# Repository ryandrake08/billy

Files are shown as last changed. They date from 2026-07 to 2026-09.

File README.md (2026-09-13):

# Smart Mouth Billy Bass LLM jokester

Billy is a Big Mouth Billy Bass novelty toy converted into an **offline, LAN-only** voice
jokester. An ESP32-S3 inside the fish captures speech, drives the motors, and plays back
audio; a separate GPU box does speech-to-text, LLM inference, and text-to-speech. There is no
internet dependency anywhere in the pipeline.

The fish's' persona, conversation history, text cleanup, and configuraion all live on the
backend, in an business-logic "shim" application in front of the LLM. The fish just captures
audio, makes three HTTP calls per turn, plays the reply, and animates the mouth/head/tail in
sync with it.

## Architecture

```
        FISH (ESP32-S3)                                BACKEND (LAN)
  ┌──────────────────────────┐                  ┌───────────────────────────┐
  │ mic → capture utterance  │─── utterance ───▶│ whisper.cpp        :8081  │
  │                          │◀───── text ──────│                           │
  |                          |                  |                           |    ┌─────────────────┐
  │ text → shim              │────── text ─────▶│ shim (persona,     :8000  │──▶ | llama.cpp :8080 |
  │                          │◀─── response ────│  history, text cleaning)  │    └─────────────────┘
  │                          │                  │                           │
  │ sentence → TTS           │──── sentence ───▶│ Kokoro             :8880  │
  │                          │◀──── audio ──────│                           │
  │ amp + motors             │                  └───────────────────────────┘
  └──────────────────────────┘
```

Three calls per conversational turn:

| Call | Target | Request → Response |
|---|---|---|
| STT | whisper.cpp `:8081`, direct | `POST /inference` (multipart wav, `response_format=verbose_json`, `language=auto`) → `{"text", "detected_language", ...}` |
| brain | shim `:8000` | `POST /v1/respond` `{session, text, language}` → SSE stream of `{"sentence", "voice"}` |
| TTS | Kokoro `:8880`, direct | `POST /v1/audio/speech` `{model, input, voice}` → wav bytes |

STT and TTS are dumb audio↔text transforms called **directly**; only the brain hop goes through
the shim, which is a text-only service that never touches audio. The shim streams sentences as
the LLM generates them, so the caller can synthesize and play sentence 1 while sentence 2 is
still being generated — this pipelining is what keeps time-to-first-audio low.

There are three implementations of this protocol, and they should be indentical: the reference clients
`src/client/billy_cli.py` (Python) and `src/cli/` (C), and the ESP32 firmware
(`src/firmware/main/net.c`). The CLIs exist to document the protocol the firmware has to match —
the C one doubles as a check on how much of the firmware's own protocol code (WAV header,
hand-rolled JSON parsing, SSE reassembly) is genuinely ESP-IDF-independent and portable to a
host build; it turned out to be all of it.

## Repository layout

| Path | What |
|---|---|
| `board/` | Custom PCB for the fish's electronics (KiCad). |
| `src/firmware/` | ESP32-S3 firmware (C, ESP-IDF). |
| `src/shim/` | Backend application-logic layer (Python/FastAPI). |
| `src/client/` | CLI reference client (Python) — a mic+speaker stand-in for the fish. |
| `src/cli/` | CLI reference client (C) — built against libcurl/PortAudio/soxr. |
| `src/tests/` | End-to-end integration test for the multi-language STT→shim→LLM pipeline. |

---

## `board/` — Custom PCB

KiCad project at `board/billy/`. Replaces the toy's stock control board with a single board
carrying the ESP32-S3, motor drivers, amp, buck regulator, and power-input protection,
designed to fit inside the original toy's chassis (~70×50mm).

| Part | Role |
|---|---|
| ESP32-S3-WROOM-1-N4R2 | Controller — WiFi, dual I²S, deep sleep |
| TDK ICS-43434 (I²S MEMS mic) | Microphone — mounted as a separate satellite board, off the main PCB, for acoustic placement |
| MAX98357A (I²S class-D amp) | Speaker drive |
| 2× TI DRV8833 (dual H-bridge) | 3 motor channels — mouth, head, tail (all spring-return, unidirectional) |
| DIODES AP63203 buck | 6V → 3.3V logic/audio rail |
| AOS AO3401A / AO3400A FETs (battery reverse-polarity protection, USB/motor-rail isolation pass FET, status LED + photocell/Vmotor-sense divider gating) | Power-input protection and deep-sleep peripheral gating |
| Analog Devices LTC4412 | Ideal-diode controller — motor rail vs. USB arbitration into the buck |
| MCC B5817W Schottky | Passive ideal diode — USB VBUS into the buck |
| 2× 5A slow-blow fuses | Battery and DC-jack input protection |

The KiCad schematic and PCB are authoritative for hardware connectivity and layout. Firmware
`board.h` mirrors the schematic's GPIO assignments and must stay synchronized with it.

**Workflow:**
```bash
open board/billy/billy.kicad_pro
kicad-cli sch erc --format json --severity-all -o erc.json board/billy/billy.kicad_sch
kicad-cli pcb drc --format json --severity-all --schematic-parity -o drc.json board/billy/billy.kicad_pcb
```

---

## `src/firmware/` — ESP32-S3 firmware

Captures speech, calls the backend for STT → LLM → TTS, plays the reply, and drives the
mouth/head/tail motors in sync with it. Targets `esp32s3` (tested with ESP-IDF v6.0.2).

### Layering

| Layer | Files | Responsibility |
|---|---|---|
| app | `main.c` | `app_main()` wires everything together; `runloop_task` runs the `IDLE→ACTIVATE→LISTEN→THINK→SPEAK→IDLE` state machine. |
| transport | `net.c/.h` | The fish↔backend contract described above — STT direct, brain hop through the shim, TTS direct. |
| device | `audio.c/.h`, `motors.c/.h`, `activation.c/.h`, `peripherals.c/.h` | Fish-specific setup and algorithms built on the HAL: I²S mic/amp + mouth lip-sync envelope; 2× DRV8833 motor choreography with `nFAULT` telemetry and deferred Vmotor capture; button/mode-switch/wake-word activation + deep sleep; WS2812 status LED + photocell/Vmotor-sense reads, all gated by one shared enable line. |
| HAL | `hal.c/.h` | Generic, pin-parameterized primitives (GPIO, ADC1, LED strip, PWM, I²S, deep sleep) with no fish-specific naming and no `board.h` dependency of its own. |

`board.h` is the firmware representation of the schematic pin map. `components/wakeword` is the on-device
wake-word detector (TensorFlow Lite Micro, ported from ESPHome's `micro_wake_word` component). See its own
`models/ATTRIBUTION.md` for training provenance.

### Build

```bash
source ~/.espressif/tools/activate_idf_v6.0.2.sh
cd src/firmware
export WIFI_SSID="your-2.4GHz-ssid" WIFI_PASSWORD="your-password" BACKEND_HOST="your-backend-hostname-or-ip"
idf.py set-target esp32s3      # once
idf.py build
idf.py -p <port> flash monitor
```
WiFi credentials and the backend host are build-environment variables injected as compile
definitions (`main/CMakeLists.txt`). Changing one needs `idf.py reconfigure`. `./clean.sh`
removes all generated build state.

### Debug

Step-debug with breakpoints over the S3's native USB-Serial-JTAG:
```bash
openocd -f board/esp32s3-builtin.cfg    # terminal 1
idf.py -p <port> gdb                    # terminal 2
```
The DevKitC-1 has two USB ports — flashing uses the UART/CP2102 port; OpenOCD needs the
separate native-USB port instead. The production board has a USB port and a three pin
header (TTL level) to one of the ESP32's built-in UARTs. Only use a USB-to-UART cable that
uses 3.3V with this header! In addition to the direct-to-UART header, the production board
has a two pin header for firmware flashing. Jumping the header during a reset causes the chip
to enter UART download (flashing) mode instead of booting normally from flash memory.
The UART/FLASH headers are intended to be a backup in case flashing over USB fails, and the
header can be left unpopulated if unused.

### Runtime behavior

`runloop_task` starts immediately on boot and idles waiting for activation; it does not block
on WiFi or the backend being reachable. Activation depends on the mode switch: **button mode**
(press-to-talk, deep-sleeps between turns) or **wake-word mode** (mic stays live, listens for
"hey billy"; a button press also works as a manual override). Flipping the switch mid-wait
preempts immediately. Runtime-tunable constants (VAD thresholds, mouth/tail timing, and HTTP
timeouts) are fetched from the shim's `/v1/config` every loop cycle rather than compiled
in, with compiled-in fallbacks if the shim is unreachable. Each capture's VAD threshold adapts
to the room's ambient noise level, measured during the pre-capture drain window, so a noisy
room still reads as silence once the user stops talking. The DRV8833 `nFAULT` line is logged but
does not gate motor commands because it asserts unreliably on the board; the drivers' independent
silicon overcurrent, thermal, and undervoltage protection remains active.

---

## `src/shim/` — backend application-logic layer

The brain layer in front of `llama.cpp`. Holds the application logic that has to live off the
fish for it to stay a thin client:

- **persona** / system prompt — edit `text.py`, reload;
- **conversation history / session state** — kept server-side, keyed by session id;
- **model quirks** — the `enable_thinking` request flag and `<think>`-block stripping;
- **markdown/emoji scrubbing** — the LLM still emits stray formatting that TTS would mangle;
- **sentence splitting + streaming** — emits clean sentences as they're ready so the caller can
  pipeline TTS for low first-audio latency;
- **per-language voice routing** (`text.py`'s `LANGUAGE_VOICES`) — English (`am_onyx`) plus
  Spanish, Brazilian Portuguese, Mandarin, Japanese, Hindi, and Italian, picked from the caller's
  detected language and overridable per sentence for an explicit switch mid-reply;
- **runtime firmware config** (`fish_config.py`) — tunable firmware constants served over
  `GET /v1/config`, so they can be retuned without a reflash.

### Protocol

| Call | Request | Response |
|---|---|---|
| `POST /v1/respond` | `{"session": "default", "text": "<user utterance>", "language": "english"}` | `text/event-stream`: one `data: {"sentence": ..., "voice": ...}` per spoken sentence, then `data: [DONE]` |
| `POST /v1/reset` | `{"session": "default"}` | `{"reset": "<session>"}` |
| `GET /v1/config` | — | Runtime firmware-tunable constants |
| `GET /health` | — | `{status, llm_url, llm_model, llm_reachable, sessions}` |

### Run

```bash
cd src/shim
python3 -m venv .venv && .venv/bin/pip install -r requirements.txt
.venv/bin/uvicorn billy_shim:app --host 0.0.0.0 --port 8000
```
Config via env: `BILLY_LLM_URL` (default `http://localhost:8080`), `BILLY_LLM_MODEL` (default
`Qwen3.5-9B`). Tests use plain asserts rather than pytest:

```bash
.venv/bin/python test_text.py
.venv/bin/python test_config.py
.venv/bin/python test_session.py
```

### Deploy

Shim program can live anywhere. Recommend using your OS's init system to start and manage it.

---

## `src/client/` — CLI reference client (Python)

A command-line stand-in for the fish: drives the full backend pipeline (record → STT → shim →
TTS → play) from any host with a mic and speaker.

### Run

```bash
cd src/client
python3 -m venv .venv && . .venv/bin/activate && pip install -r requirements.txt
./billy_cli.py --host <backend-host>     # ports 8000/8081/8880 derived from host
```
Press **Enter** to start talking, speak, press **Enter** to stop. `Ctrl-C` quits.

`--voice <kokoro-voice>` overrides the voice for the whole session (browse the list at
`http://<backend-host>:8880/web`); otherwise each sentence uses the shim's own per-sentence
choice. `--session <id>` sets the shim conversation id; `--shim-url`/`--stt-url`/`--tts-url`
override individual endpoints. Uses the system default audio devices.

`--input-wav <path>` skips the mic entirely: runs one turn on that WAV file's bytes (16 kHz mono,
same as the mic path itself records) and exits — for testing the same utterance repeatedly
without re-recording it by hand each time.

Each turn prints various latency measurements.

---

## `src/cli/` — CLI reference client (C)

A second, independent reference client for the same contract — same record → STT → shim → TTS →
play pipeline as the Python client, same flags, same latency breakdown, but built as a plain C
binary via CMake instead of a Python venv.

External dependencies (none of this is vendored): `libcurl` (HTTP, mirrors `httpx`), `portaudio`
(mic/speaker I/O, mirrors `sounddevice`), `soxr` (output resampling, same library the Python
`soxr` package binds to). On macOS via MacPorts: `port install curl portaudio soxr`.

### Build & run

```bash
cd src/cli
cmake -S . -B build && cmake --build build
./build/billy_cli --host <backend-host>     # ports 8000/8081/8880 derived from host
```
Press **Enter** to start talking, speak, press **Enter** to stop. `Ctrl-C` quits, same as the
Python client.

Same `--voice`/`--session`/`--shim-url`/`--stt-url`/`--tts-url` flags as the Python client, same
system-default audio devices. TTS audio is resampled to the output device's native rate in
software (soxr, `SOXR_HQ` quality).

---

## `src/tests/` — end-to-end integration test

Exercises the  STT→shim→LLM chain for every supported language. For each language, a
"golden" WAV asking Billy to repeat a fixed phrase is transcribed by real whisper.cpp, then sent
to a shim, checking the reply comes back in the right voice and language.

```bash
cd src/tests
python3 -m venv .venv && .venv/bin/pip install -r requirements.txt
./.venv/bin/python test_language_integration.py     # needs src/shim/.venv already set up
```

The golden WAVs in `golden/` are gitignored: `generate_golden.py` makes them with Microsoft's
free `edge-tts`. The test does this itself the first time golden/ is missing a file.

---

## Backend engines

Three off-the-shelf inference engines run on the backend GPU host alongside the shim, all under
systemd (`Restart=always`, enabled at boot):

| Service | Port | Model | GPU |
|---|---|---|---|
| llama.cpp | 8080 | Qwen3.5-9B, Q8_0, non-thinking mode | yes |
| whisper.cpp | 8081 | `large-v3` | yes |
| Kokoro (Kokoro-FastAPI) | 8880 | `am_onyx` + 6 other language voices (see `src/shim/`) | yes |

All three plus the shim are expected to fit resident in ~14GB of VRAM.

---

## License

Source code and documentation are licensed under [Apache License 2.0](LICENSE). The
trained wake-word model `src/firmware/components/wakeword/models/hey_billy.tflite` is
explicitly excluded; see [NOTICE](NOTICE) and its
[`ATTRIBUTION.md`](src/firmware/components/wakeword/models/ATTRIBUTION.md).

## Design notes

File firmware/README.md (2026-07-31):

# Billy fish firmware (ESP32-S3)

The on-fish firmware. Captures speech, calls the backend for STT → LLM → TTS, plays the reply,
and drives the mouth/head/tail motors in sync with it. Runs on an ESP32-S3-WROOM-1 N8R8, target
`esp32s3`, no persona or conversation state on-device — see the top-level `CLAUDE.md` for how this
fits into the rest of the project.

## Layering

Three layers, each with a single responsibility:

| Layer | Files | Responsibility |
|---|---|---|
| **app** | `main.c` | `app_main()` wires the layers together; `runloop_task` runs the `IDLE→ACTIVATE→LISTEN→THINK→SPEAK→IDLE` state machine. |
| **transport** | `net.c/.h` | The fish↔backend contract — STT (whisper), brain (shim), TTS (Kokoro). WiFi join/reconnect is async and unbounded, supervised by a dedicated task for the app's whole runtime. |
| **hardware** | `hal.c/.h`, `board.h`, `components/wakeword` | Mic/amp I²S, 2× DRV8833 motors, button/switch/photocell, wake-word detection. `board.h` is the pin map. |

The transport layer mirrors the three calls the CLI reference client makes
(`client/billy_cli.py`), so the fish reimplements the same contract.

## Build

```bash
source ~/.espressif/tools/activate_idf_v6.0.2.sh   # activate ESP-IDF v6.0.2
cd firmware

# WiFi credentials and the backend host come from the build environment, never source control
# (main/CMakeLists.txt injects them as compile definitions). BACKEND_HOST is required; export
# these BEFORE set-target — it runs a CMake configure that fails without BACKEND_HOST.
export WIFI_SSID="your-2.4GHz-ssid"
export WIFI_PASSWORD="your-password"
export BACKEND_HOST="your-host-or-ip"

idf.py set-target esp32s3      # once (configures + writes sdkconfig from sdkconfig.defaults)
idf.py build                   # without WiFi creds it warns and can't join WiFi; BACKEND_HOST is required
```

Changing an exported value needs `idf.py reconfigure` (CMake reads the environment at configure
time). Flash + watch the boot log:

```bash
idf.py -p <port> flash monitor
```

Use `./clean.sh` to remove all generated/fetched build state (`build/`, `.cache/`,
`managed_components/`, `dependencies.lock`, `sdkconfig`, `sdkconfig.old`) and start fresh.

## Debug

Step-debug with real breakpoints over the S3's native USB-Serial-JTAG, no extra hardware:

```bash
openocd -f board/esp32s3-builtin.cfg    # terminal 1 — leave running
idf.py -p <port> gdb                    # terminal 2
```

The DevKitC-1 has **two** USB-C ports — flashing via `idf.py flash` (above) uses the **UART**
port (the CP2102 bridge), but OpenOCD needs the separate **USB** port instead, wired straight to
the S3's native USB-Serial-JTAG peripheral. Plugging into the wrong port shows up as OpenOCD
failing with `could not find or open device!` — check `system_profiler SPUSBDataType` (macOS) for
a `303a:1001` device to confirm you're on the right one. That port also carries USB power, so
debug sessions have the same constraint as USB flashing: keep the battery/buck disconnected while
it's plugged in.

## Runtime behavior

`runloop_task` starts immediately on boot and idles in `FISH_IDLE` waiting for activation — it
does not wait for WiFi to join or the backend to become reachable first (look for `got IP …` in
the log once WiFi is up). A turn that needs the network before it's ready just fails that one turn
(error tone, back to idle) rather than blocking startup; a dropped connection at any point during
runtime is retried indefinitely with backoff by a dedicated task.

Activation depends on `BOARD_MODE_SW`:
- **Button mode** — a `BOARD_BUTTON` press starts a turn. Between turns the fish deep-sleeps (mic
  and status LED off, motors parked) and wakes on the next button press.
- **Wake-word mode** — the mic stays live and a turn starts on the "hey billy" phrase
  (`components/wakeword`, on-device TensorFlow Lite Micro). A button press also works here as a
  manual override.

Flipping the mode switch mid-wait preempts an in-progress wait immediately in either direction.

Each turn drives all three motors (mouth/head/tail) in sync with the reply audio and plays it
through the amp; the photocell is read at boot and available via `fish_hal_read_photocell()`, with
no consumer wired up yet. See `board.h` for the pin map and `WIRING.md` for driver and mechanism
details.

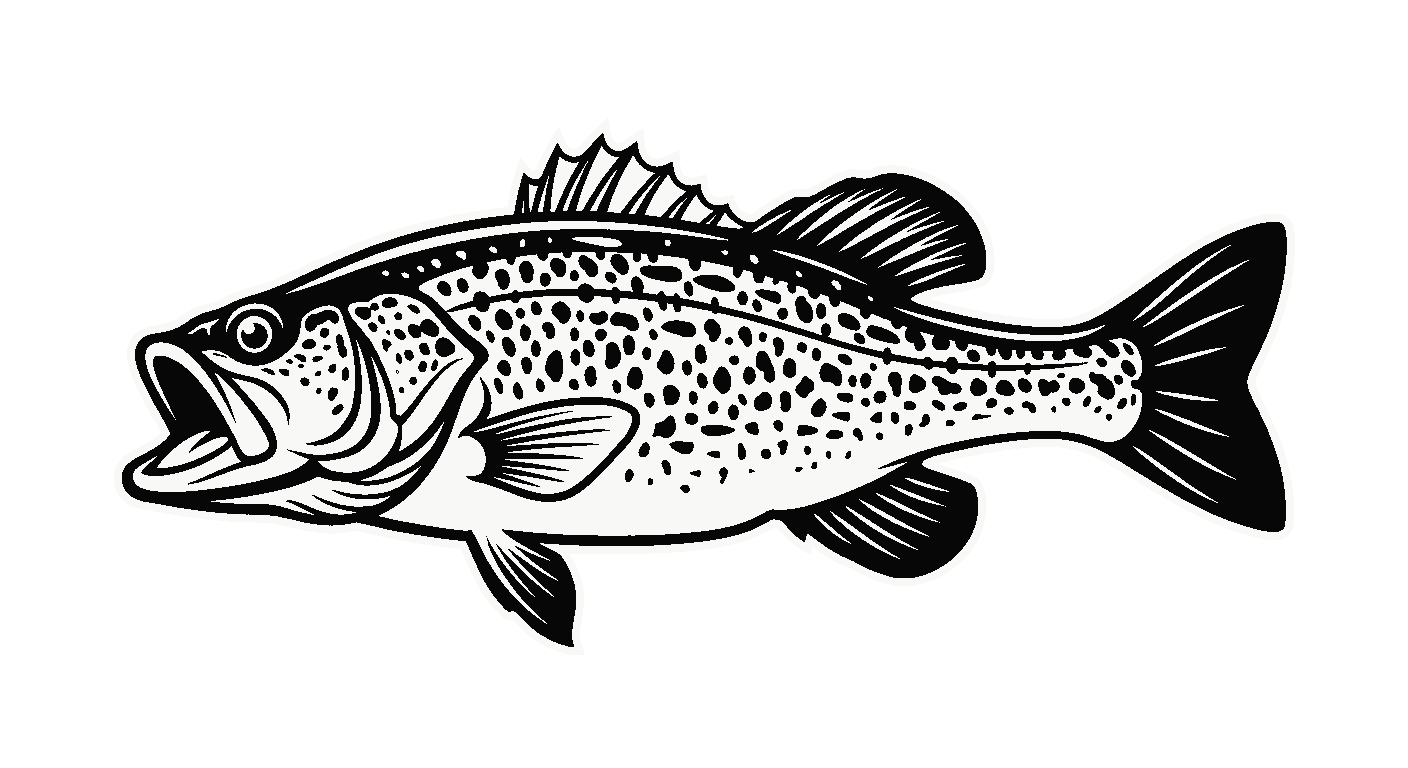
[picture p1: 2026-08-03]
board/billy/billy.png

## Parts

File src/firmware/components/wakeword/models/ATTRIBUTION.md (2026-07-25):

`hey_billy.tflite` — our own trained microWakeWord v2 model for "hey billy", trained 2026-07-24.

Training framework: `OHF-Voice/micro-wake-word` (Apache-2.0). Positive samples generated with
`rhasspy/piper-sample-generator`
(TTS, 1000 samples, `en_US-libritts_r-medium` voice); negative data from the framework's
pre-built HuggingFace sets (`speech`, `dinner_party`, `no_speech`, `dinner_party_eval`) plus MIT
room-impulse-response and FMA background-noise augmentation of the positive samples. Trained on
`gpu-host` in an isolated, disposable `/opt/training` tree — not part of this repo or the
firmware build; only this `.tflite` file is a build input.

Manifest values — keep these in sync with the `WAKEWORD_*` constants in `wakeword.cpp` if the
model is ever retrained:

```json
{
  "probability_cutoff": 0.84,
  "feature_step_size": 10,
  "sliding_window_size": 5,
  "tensor_arena_size": 33540
}
```

`probability_cutoff` chosen from the training run's ROC sweep: 5% false-reject rate, ~0.19 false
accepts/hour on the (synthetic) validation set. `sliding_window_size` matches the training
framework's own test-harness default (`microwakeword/test.py`, `sliding_window_length=5`).
`tensor_arena_size` is measured on-device (`wakeword_init()`'s logged `arena_used_bytes()`), not
taken from any manifest — arena sizing is not portable across TFLM builds, or even between two
models on the same build. Always re-derive it empirically if the model is ever retrained.

Real-world false-accept/false-reject rates will very likely differ from the synthetic validation
numbers above — expect to retrain (more/better samples, reweighted negatives, retuned cutoff) if
bench testing shows the model is too trigger-happy or too hard to wake.

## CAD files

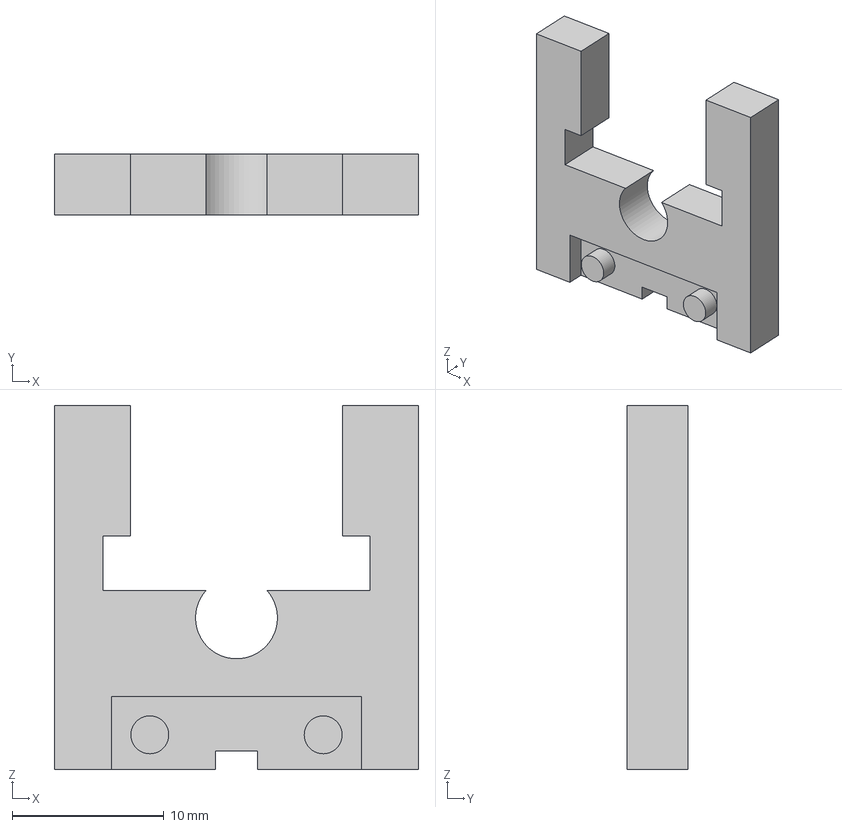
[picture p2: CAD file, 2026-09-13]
board/caddy/caddy.step
24.0 x 4.00 x 24.0 mm

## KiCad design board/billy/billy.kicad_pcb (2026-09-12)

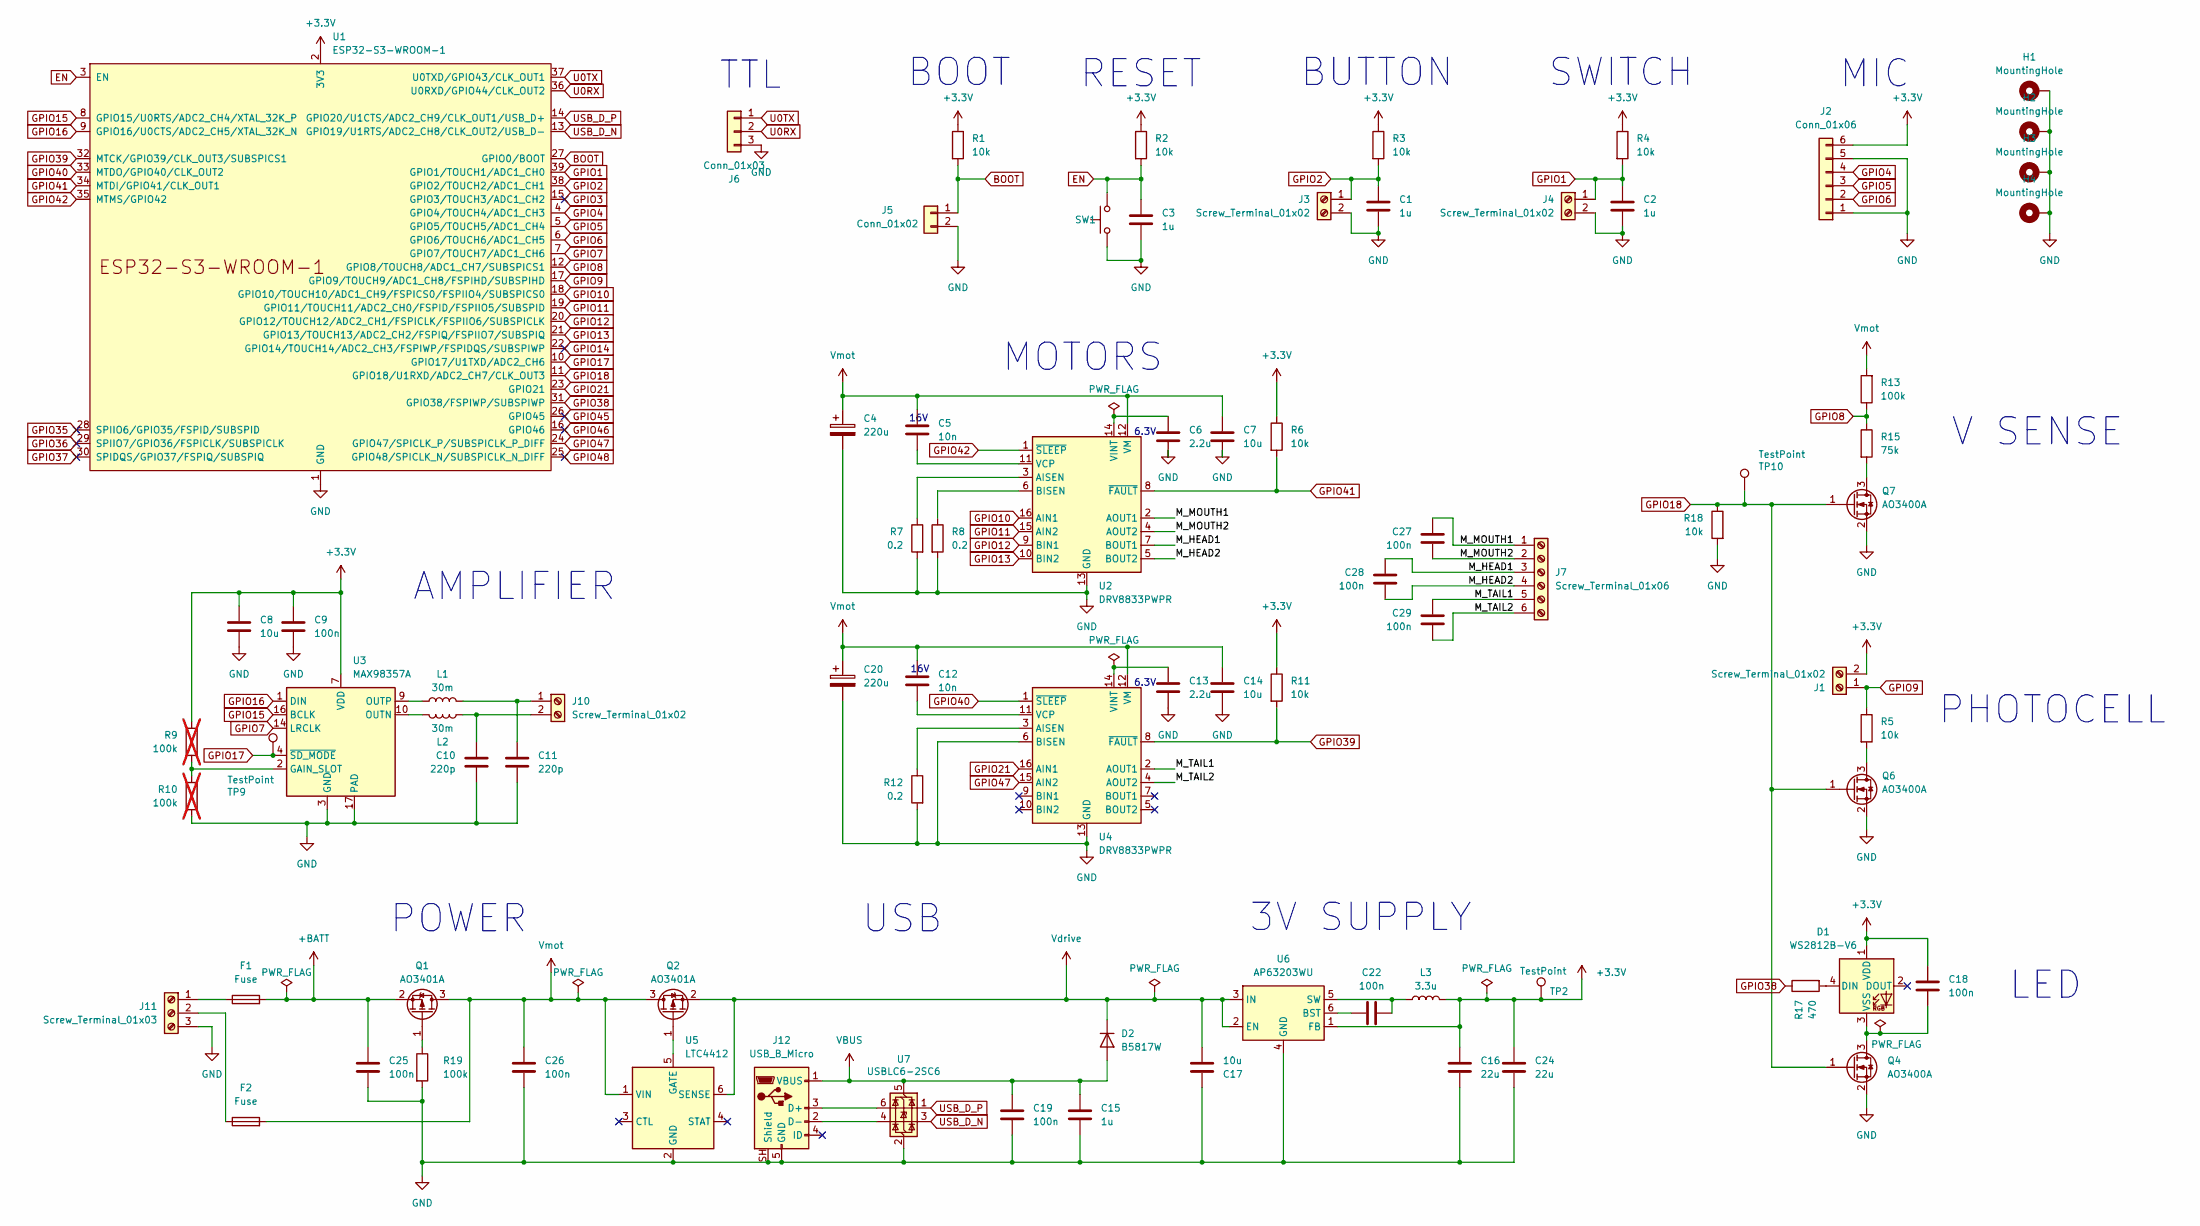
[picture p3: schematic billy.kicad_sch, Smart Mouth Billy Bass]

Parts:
C1, C2, C3, C15: 1u; C_0603_1608Metric; Mouser Part 187-CL10B105KP8NNNC; LCSC Part C52923
C4, C20: 220u; CP_Elec_6.3x5.9; Mouser Part 667-EEE-FT1C221AP; LCSC Part C401766
C5, C12: 10n; C_0603_1608Metric; Mouser Part 187-CL05B103KB5NNNC; LCSC Part C15195
C6, C13: 2.2u; C_0603_1608Metric; Mouser Part 187-CL10A225KP8NNNC; LCSC Part C23630
C7, C8, C14: 10u; C_0603_1608Metric; Mouser Part 187-CL10A106KP8NNND; LCSC Part C19702
C9, C18, C19, C22, C25, C26, C27, C28, C29: 100n; C_0603_1608Metric; Mouser Part 187-CL10B104JB8NNNC; LCSC Part C1525
C10, C11: 220p; C_0603_1608Metric; Mouser Part 187-CL10B221KB8NNNC; LCSC Part C1530
C16, C24: 22u; C_1206_3216Metric; Mouser Part 187-CL31B226KPHNNNE; LCSC Part C45783
C17: 10u; C_1206_3216Metric; Mouser Part 187-CL31B106KLHNNNE; LCSC Part C45783
D1: WS2812B-V6; LED_WS2812B_PLCC4_5.0x5.0mm_P3.2mm; LCSC Part C52941391
D2: B5817W; D_SOD-323; Mouser Part 833-B5817W-TP; DigiKey Part B5817WS-TPMSCT-ND
F1, F2: Fuse; Fuse_Littelfuse-NANO2-451_453; Mouser Part 576-0454005.MR; LCSC Part C206917
H1, H2, H3, H4: MountingHole; MountingHole_3.2mm_M3_ISO7380_Pad
J1, J3, J4, J10: Screw_Terminal_01x02; TerminalBlock_Xinya_XY308-2.54-2P_1x02_P2.54mm_Horizontal; Mouser Part 651-1725656; LCSC Part C918120
J2: Conn_01x06; PinHeader_1x06_P2.54mm_Horizontal; Mouser Part 710-61300611021; LCSC Part C492414
J5: Conn_01x02; PinHeader_1x02_P2.54mm_Vertical; Mouser Part 710-61300211121; LCSC Part C492401
J6: Conn_01x03; PinHeader_1x03_P2.54mm_Vertical; Mouser Part 710-61300311121; LCSC Part C2937625
J7: Screw_Terminal_01x06; TerminalBlock_Xinya_XY308-2.54-6P_1x06_P2.54mm_Horizontal; Mouser Part 651-1725698; LCSC Part C918124
J11: Screw_Terminal_01x03; TerminalBlock_Xinya_XY308-2.54-3P_1x03_P2.54mm_Horizontal; Mouser Part 651-1725669; LCSC Part C918121
J12: USB_B_Micro; USB_Micro-B_Amphenol_10118194-0001LF_Horizontal; Mouser Part 649-10118194-0001LF; LCSC Part C132563
L1, L2: 30m; L_0603_1608Metric; Mouser Part 81-BLM18KG121TN1D; LCSC Part C14709
L3: 3.3u; L_APV_ANR4030; Mouser Part 739-TYA40203R3M-10; DigiKey Part 240-TYA40203R3M-10CT-ND
Q1, Q2: AO3401A; SOT-23; LCSC Part C15127
Q4, Q6, Q7: AO3400A; SOT-23; LCSC Part C20917
R1, R2, R3, R4, R5, R6, R11, R18: 10k; R_0603_1608Metric; Mouser Part 708-RMCF0603FT10K0; LCSC Part C25804
R7, R8, R12: 0.2; R_1206_3216Metric; Mouser Part 708-CSR1206FKR200; LCSC Part C473037
R9, R10: 100k; R_0603_1608Metric; Mouser Part 708-RMCF0603FT100K; LCSC Part C25803; not fitted
R13, R19: 100k; R_0603_1608Metric; Mouser Part 708-RMCF0603FT100K; LCSC Part C25803
R15: 75k; R_0603_1608Metric; Mouser Part 708-RMCF0603FT75K0; DigiKey Part RMCF0603FT75K0CT-ND
R17: 470; R_0603_1608Metric; Mouser Part 708-RMCF0603FT470R; LCSC Part C23179
SW1: TS-1088-AR02016; SW_SPST_TS-1088-xR020; Mouser Part 688-SKRKAG; LCSC Part C720477
TP2, TP9, TP10: TestPoint; TestPoint_Pad_1.0x1.0mm
U1: ESP32-S3-WROOM-1; Mouser Part 356-ESP32S3WROM1N4R2; LCSC Part C2913203
U2, U4: DRV8833PWPR; HTSSOP-16-1EP_4.4x5mm_P0.65mm_EP3.4x5mm; Mouser Part 595-DRV8833PWPR; LCSC Part C50506
U3: MAX98357A; TQFN-16-1EP_3x3mm_P0.5mm_EP1.23x1.23mm; Mouser Part 700-MAX98357AETE+T; LCSC Part C910544
U5: LTC4412; TSOT-23-6; Mouser Part 584-LTC4412ES6TRMPBF; DigiKey Part 505-LTC4412ES6#TRMPBFCT-ND
U6: AP63203WU; TSOT-23-6; Mouser Part 621-AP63203QWU-7; LCSC Part C780769
U7: USBLC6-2SC6; SOT-23-6; Mouser Part 511-USBLC6-2SC6; LCSC Part C7519

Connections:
+3.3V: C8.1, C9.1, C16.1, C18.1, C24.1, D1.1 (VDD), J1.2, J2.6, L3.2, R1.1, R2.1, R3.1, R4.1, R6.1, R9.1, R11.1, TP2.1 (1_1), U1.2 (3V3), U3.7 (VDD), U3.8 (VDD), U6.1 (FB)
+BATT: C25.1, F1.2, Q1.2 (S)
/M_HEAD1: C28.1, J7.3, U2.7 (BOUT1)
/M_HEAD2: C28.2, J7.4, U2.5 (BOUT2)
/M_MOUTH1: C27.1, J7.1, U2.2 (AOUT1)
/M_MOUTH2: C27.2, J7.2, U2.4 (AOUT2)
/M_TAIL1: C29.2, J7.5, U4.2 (AOUT1)
/M_TAIL2: C29.1, J7.6, U4.4 (AOUT2)
BOOT: J5.1, R1.2, U1.27 (GPIO0/BOOT)
EN: C3.1, R2.2, SW1.2, U1.3 (EN)
GND: C1.2, C2.2, C3.2, C4.2, C6.2, C7.2, C8.2, C9.2, C10.2, C11.2, C13.2, C14.2, C15.2, C16.2, C17.2, C19.2, C20.2, C24.2, C25.2, C26.2, H1.1 (1_1), H2.1 (1_1), H3.1 (1_1), H4.1 (1_1), J2.1, J2.5, J3.2, J4.2, J5.2, J6.3, J11.3, J12.5 (GND), J12.SH (Shield), Q4.2 (S), Q6.2 (S), Q7.2 (S), R7.2, R8.2, R10.2, R12.2, R18.2, R19.2, SW1.1, U1.1 (GND), U1.40 (GND), U1.41 (GND), U2.13 (GND), U2.17 (GND), U3.3 (GND), U3.11 (GND), U3.15 (GND), U3.17 (PAD), U4.6 (BISEN), U4.13 (GND), U4.17 (GND), U5.2 (GND), U6.4 (GND), U7.2 (GND)
GPIO1: C2.1, J4.1, R4.2, U1.39 (GPIO1/TOUCH1/ADC1_CH0)
GPIO2: C1.1, J3.1, R3.2, U1.38 (GPIO2/TOUCH2/ADC1_CH1)
GPIO3: U1.15 (GPIO3/TOUCH3/ADC1_CH2)
GPIO4: J2.4, U1.4 (GPIO4/TOUCH4/ADC1_CH3)
GPIO5: J2.3, U1.5 (GPIO5/TOUCH5/ADC1_CH4)
GPIO6: J2.2, U1.6 (GPIO6/TOUCH6/ADC1_CH5)
GPIO7: U1.7 (GPIO7/TOUCH7/ADC1_CH6), U3.14 (LRCLK)
GPIO8: R13.1, R15.1, U1.12 (GPIO8/TOUCH8/ADC1_CH7/SUBSPICS1)
GPIO9: J1.1, R5.1, U1.17 (GPIO9/TOUCH9/ADC1_CH8/FSPIHD/SUBSPIHD)
GPIO10: U1.18 (GPIO10/TOUCH10/ADC1_CH9/FSPICS0/FSPIIO4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), U2.16 (AIN1)
GPIO11: U1.19 (GPIO11/TOUCH11/ADC2_CH0/FSPID/FSPIIO5/S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), U2.15 (AIN2)
GPIO12: U1.20 (GPIO12/TOUCH12/ADC2_CH1/FSPICLK/FSPIIO6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), U2.9 (BIN1)
GPIO13: U1.21 (GPIO13/TOUCH13/ADC2_CH2/FSPIQ/FSPIIO7/S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), U2.10 (BIN2)
GPIO14: U1.22 (GPIO14/TOUCH14/ADC2_CH3/FSPIWP/FSPIDQS/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)
GPIO15: U1.8 (GPIO15/U0RTS/ADC2_CH4/XTAL_32K_P), U3.16 (BCLK)
GPIO16: U1.9 (GPIO16/U0CTS/ADC2_CH5/XTAL_32K_N), U3.1 (DIN)
GPIO17: TP9.1 (1_1), U1.10 (GPIO17/U1TXD/ADC2_CH6), U3.4 (~SD_MODE)
GPIO18: Q4.1 (G), Q6.1 (G), Q7.1 (G), R18.1, TP10.1 (1_1), U1.11 (GPIO18/U1RXD/ADC2_CH7/CLK_OUT3)
GPIO21: U1.23 (GPIO21), U4.16 (AIN1)
GPIO35: U1.28 (SPIIO6/GPIO35/FSPID/SUBSPID)
GPIO36: U1.29 (SPIIO7/GPIO36/FSPICLK/SUBSPICLK)
GPIO37: U1.30 (SPIDQS/GPIO37/FSPIQ/SUBSPIQ)
GPIO38: R17.1, U1.31 (GPIO38/FSPIWP/SUBSPIWP)
GPIO39: R11.2, U1.32 (MTCK/GPIO39/CLK_OUT3/SUBSPICS1), U4.8 (~FAULT)
GPIO40: U1.33 (MTDO/GPIO40/CLK_OUT2), U4.1 (~SLEEP)
GPIO41: R6.2, U1.34 (MTDI/GPIO41/CLK_OUT1), U2.8 (~FAULT)
GPIO42: U1.35 (MTMS/GPIO42), U2.1 (~SLEEP)
GPIO45: U1.26 (GPIO45)
GPIO46: U1.16 (GPIO46)
GPIO47: U1.24 (GPIO47/SPICLK_P/SUBSPICLK_P_DIFF), U4.15 (AIN2)
GPIO48: U1.25 (GPIO48/SPICLK_N/SUBSPICLK_N_DIFF)
unnamed: D1.4 (DIN), R17.2
unnamed: C18.2, D1.3 (VSS), Q4.3 (D)
unnamed: C11.1, J10.1, L1.2
unnamed: C10.1, J10.2, L2.1
unnamed: F1.1, J11.1
unnamed: F2.1, J11.2
unnamed: J12.3 (D+), U7.6 (I/O1)
unnamed: J12.2 (D-), U7.4 (I/O2)
unnamed: Q1.1 (G), R19.1
unnamed: Q2.1 (G), U5.5 (GATE)
unnamed: Q6.3 (D), R5.2
unnamed: Q7.3 (D), R15.2
unnamed: R7.1, U2.3 (AISEN)
unnamed: R8.1, U2.6 (BISEN)
unnamed: C5.2, U2.11 (VCP)
unnamed: C6.1, U2.14 (VINT)
unnamed: R9.2, R10.1, U3.2 (GAIN_SLOT)
unnamed: L2.2, U3.10 (OUTN)
unnamed: L1.1, U3.9 (OUTP)
unnamed: R12.1, U4.3 (AISEN)
unnamed: C12.2, U4.11 (VCP)
unnamed: C13.1, U4.14 (VINT)
unnamed: C22.1, U6.6 (BST)
unnamed: C22.2, L3.1, U6.5 (SW)
U0RX: J6.2, U1.36 (U0RXD/GPIO44/CLK_OUT2)
U0TX: J6.1, U1.37 (U0TXD/GPIO43/CLK_OUT1)
USB_D_N: U1.13 (GPIO19/U1RTS/ADC2_CH8/CLK_OUT2/USB_D-), U7.3 (I/O2)
USB_D_P: U1.14 (GPIO20/U1CTS/ADC2_CH9/CLK_OUT1/USB_D+), U7.1 (I/O1)
VBUS: C15.1, C19.1, D2.2 (A), J12.1 (VBUS), U7.5 (VBUS)
Vdrive: C17.1, D2.1 (K), Q2.2 (S), U5.6 (SENSE), U6.2 (EN), U6.3 (IN)
Vmot: C4.1, C5.1, C7.1, C12.1, C14.1, C20.1, C26.1, F2.2, Q1.3 (D), Q2.3 (D), R13.2, U2.12 (VM), U4.12 (VM), U5.1 (VIN)

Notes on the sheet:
SWITCH
16V
LED
AMPLIFIER
3V SUPPLY
USB
TTL
BOOT
RESET
MIC
POWER
PHOTOCELL
V SENSE
BUTTON
6.3V
MOTORS

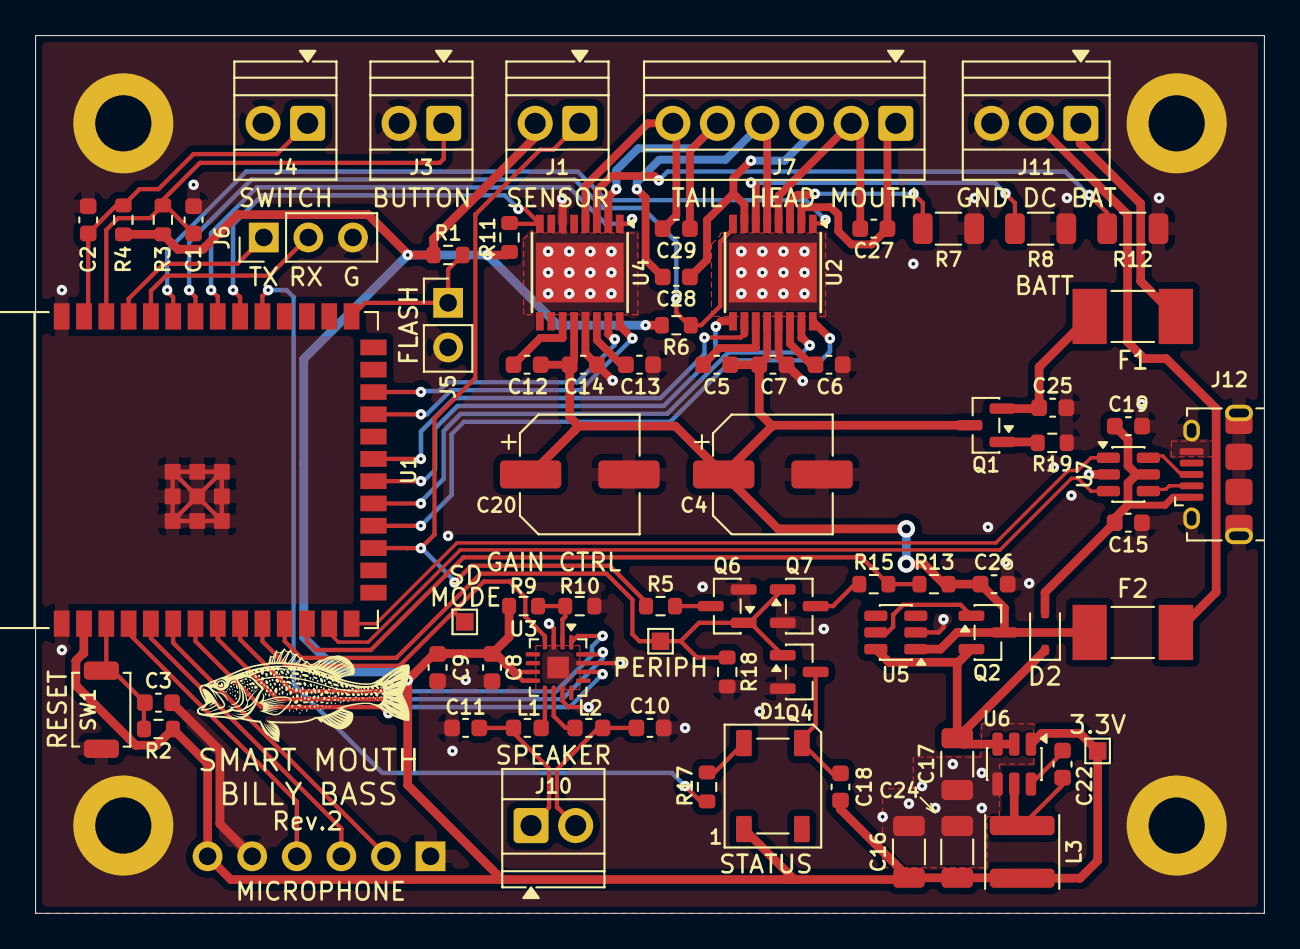
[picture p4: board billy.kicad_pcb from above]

Board: 2 copper layers, 70.0 x 50.0 mm, 81 parts (1 on the bottom side), 65 nets.

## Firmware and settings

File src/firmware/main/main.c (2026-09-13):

// Billy fish firmware — entry point and top-level turn loop.
#include "audio.h"
#include "motors.h"
#include "activation.h"
#include "peripherals.h"
#include "net.h"
#include "wakeword.h"
#include "fish_config.h"

#include "freertos/FreeRTOS.h"
#include "freertos/task.h"
#include "esp_heap_caps.h"
#include "esp_log.h"
#include "esp_system.h"
#include <stdbool.h>

static const char *TAG = "billy";

static void signal_motor_fault(void)
{
    peripherals_set_led_status(LED_STATUS_ERROR);
    audio_error_tone();
}

// SPEAK worker: synthesize one streamed sentence and play it with mouth sync. Invoked by
// net_respond for each sentence, so playback pipelines with generation. Propagates (net_respond
// stops the stream and passes it up) for conditions the runloop needs to reboot over -- playback
// hardware failure or PSRAM exhaustion, which require a reboot, and a motor fault, which aborts
// the rest of the reply so the run loop can present the local safety error. Any ordinary TTS
// failure is handled locally (tone + keep going) since it's a per-sentence network hiccup.
static esp_err_t speak_sentence(const char *sentence, const char *voice, void *ctx)
{
    (void) ctx;
    audio_buf_t audio = {0};
    esp_err_t err = net_tts(sentence, voice, &audio);
    if (err != ESP_OK && err != ESP_ERR_NO_MEM)
    {
        // Backend/network failure, not "nothing to say" -- distinct cue so the user doesn't
        // think the fish just finished speaking normally. Recoverable, so swallow it here rather
        // than propagating: net_respond keeps streaming the rest of the reply.
        ESP_LOGW(TAG, "TTS failed for sentence: \"%s\"", sentence);
        audio_error_tone();
        err = ESP_OK;
    }
    else if (err == ESP_OK && audio.count > 0)
    {
        err = audio_play(&audio);
    }
    heap_caps_free(audio.samples);
    return err;
}

// The turn loop task body: idle -> listen -> transcribe -> speak -> idle, driving the HAL and
// transport layers. Runs on its own task (see app_main) — the per-turn work nests net_respond's
// SSE reader over net_tts and playback, plus esp_http_client under each, so it needs far more
// stack than the main task's ~3.5 KB default.
static void runloop_task(void *arg)
{
    (void) arg;

    // We need to skip the idle wait if the user pushed the button and the device booted out of
    // deep sleep mode, and the photocell doesn't reject it as a dark-room false positive. Default
    // is to not skip the idle wait.
    bool skip_idle = false;

    // Read the raw wake pin first, before deciding whether to skip idle below.
    wake_pin_t wake_pin = activation_deep_sleep_wake_pin();
    if (wake_pin == WAKE_PIN_BUTTON)
    {
        ESP_LOGI(TAG, "deep-sleep boot: button pushed");

        // Test the photocell brightness to filter out false positives. If the room is bright
        // enough, we have a true activation-from-boot and need to skip the idle wait.
        skip_idle = peripherals_photocell_bright_enough();
    }

    if (wake_pin == WAKE_PIN_MODE_SW)
    {
        ESP_LOGI(TAG, "deep-sleep boot: mode switch flipped");
    }

    for (;;)
    {
        // A single best-effort, bounded attempt -- must never meaningfully delay sleep or a
        // WAKEWORD-mode loop. If it fails because WiFi is not available or the server doesn't
        // respond, no big deal. We'll retry next turn.
        net_fetch_config(/* wait_for_backend = */ false);

        if (!skip_idle)
        {
            // Idle state -- fish is waiting to be activated.
            // In button mode, this is a deep sleep. Activating the button or switch will boot the device
            // In wakeword mode, activating the button or wakeword will continue to the next state
            // In wakeword mode, activating the switch will interrupt the wait and return back to idle
            peripherals_set_led_status(LED_STATUS_IDLE);
            activation_prepare_sleep();
            activation_event_t event = activation_wait();
            if (event == ACTIVATION_MODE_SW)
            {
                // The mode switch flipped -- loop back so the next pass prepares and waits using
                // the newly selected mode.
                continue;
            }

            // A dark room rules the candidate out as a likely false positive -- a flaky button
            // contact, or background noise misfiring the wake-word detector -- rather than a
            // deliberate activation.
            if (!peripherals_photocell_bright_enough())
            {
                continue;
            }
        }
        skip_idle = false;

        // A fault remains latched for the rest of its turn, but only for the group it hit.
        // Only a fresh user activation may attempt recovery, with every PWM command cleared
        // and nFAULT checked around driver wake.
        if (!motors_recover_if_faulted(MOTORS_GROUP_TAIL))
        {
            signal_motor_fault();
            continue;
        }

        // Prepare to listen
        peripherals_set_led_status(LED_STATUS_LISTEN);

        // Prompt the user audibly
        audio_prompt_tone();

        // Try to flap the tail to indicate it's listening
        if (!motors_tail_flap())
        {
            signal_motor_fault();
            continue;
        }

        // Capture an utterance from the microphone
        audio_buf_t utterance = {0};
        if (audio_capture_utterance(&utterance) != ESP_OK)   // blocks until speech, then silence
        {
            // PSRAM allocation failure -- not worth retrying capture again against the same
            // exhausted heap. A fresh boot clears that heap state entirely, so recover by
            // rebooting rather than halting; flash the error status first so it's visible
            // even though the reboot (and BUTTON mode's own deep-sleep reboots) will clear it.
            peripherals_set_led_status(LED_STATUS_ERROR);
            ESP_LOGE(TAG, "capture failed (PSRAM allocation) — rebooting");
            esp_restart();
        }

        // Transcribe the utterance using speech-to-text backend
        peripherals_set_led_status(LED_STATUS_THINK);
        char transcript[256];
        char language[64];
        esp_err_t stt_err = net_stt(&utterance, transcript, sizeof transcript,
                                     language, sizeof language);
        heap_caps_free(utterance.samples);   // PCM no longer needed after STT

        if (stt_err == ESP_ERR_NO_MEM)
        {
            // Same device-wide, will-just-recur condition as the capture failure above -- reboot
            // rather than tone-and-retry into the same exhausted heap.
            peripherals_set_led_status(LED_STATUS_ERROR);
            ESP_LOGE(TAG, "STT failed (heap/PSRAM exhausted) — rebooting");
            esp_restart();
        }
        else if (stt_err != ESP_OK)
        {
            // Backend/network failure, not "nothing to say" -- distinct cue so the user doesn't
            // think the fish just didn't hear them and repeat themselves into the same failure.
            ESP_LOGW(TAG, "STT failed — back to idle");
            audio_error_tone();
            continue;
        }

        if (transcript[0] == '\0')
        {
            // Covers both real silence and a capture abandoned partway through by a button press
            // (audio_capture_utterance() returns a zeroed buffer for either) -- both are normal,
            // not errors, and both just need a plain trip back to idle.
            ESP_LOGI(TAG, "heard nothing — back to idle");
            continue;
        }

        // Prepare to speak
        peripherals_set_led_status(LED_STATUS_SPEAK);

        // Pass utterance transcript to LLM backend shim app
        if (!motors_recover_if_faulted(MOTORS_GROUP_MOUTH_HEAD))
        {
            signal_motor_fault();
            continue;
        }

        // Try to extend the head for it to speak
        if (!motors_head_out())
        {
            signal_motor_fault();
            continue;
        }

        // The shim streams sentences; speak_sentence TTS+plays each as it arrives.
        esp_err_t respond_err = net_respond(transcript, language, speak_sentence, NULL);
        if (respond_err == FISH_ERR_AUDIO_HW || respond_err == ESP_ERR_NO_MEM)
        {
            // Both are device-wide conditions that will just recur on the next sentence -- the
            // speaker is broken, or PSRAM is exhausted -- so playing the usual error tone (which
            // itself may need PSRAM/the speaker) and continuing is pointless. A fresh boot clears
            // heap state and re-inits the amp/I2S from scratch, same rationale as the
            // capture-failure reboot above.
            peripherals_set_led_status(LED_STATUS_ERROR);
            ESP_LOGE(TAG, "unrecoverable TTS/playback failure (%s) — rebooting",
                     esp_err_to_name(respond_err));
            esp_restart();
        }
        else if (respond_err == FISH_ERR_MOTOR_FAULT)
        {
            signal_motor_fault();
            continue;
        }
        else if (respond_err != ESP_OK)
        {
            ESP_LOGW(TAG, "brain hop failed");
            audio_error_tone();
        }

        // Try to relax the head now, once the whole reply is done.
        if (!motors_head_relax())
        {
            signal_motor_fault();
            continue;
        }

        // Cumulative low-water mark since boot -- the worst-case PSRAM usage any turn has hit
        // so far, not just this one. Bench this against a 2 MB budget (N4R2 candidate) before
        // committing to it: run several turns, including a long utterance near capture_max_ms
        // and long TTS sentences, then check this log's peak-used figure stays under ~2 MB.
        ESP_LOGI(TAG, "PSRAM watermark: %u bytes peak used of %u total",
                 (unsigned) (heap_caps_get_total_size(MALLOC_CAP_SPIRAM)
                             - heap_caps_get_minimum_free_size(MALLOC_CAP_SPIRAM)),
                 (unsigned) heap_caps_get_total_size(MALLOC_CAP_SPIRAM));

        // loop back to idle
    }
}

void app_main(void)
{
    // Peripherals first (status LED + Vmotor/photocell sensing)
    // -- so a panic anywhere below (the various *_init()'s ESP_ERROR_CHECKs, etc.) still leaves
    // the status LED showing boot-white instead of unlit, giving some visible sign the chip
    // powered on at all; and so Vmotor sensing is ready before the motor fault task, letting even
    // an nFAULT line already low at boot be sampled safely in deferred task context.
    peripherals_init();

    // Initialize the remaining hardware -- each owns an independent set of pins/peripherals.
    motors_init();
    audio_init();
    activation_init();

    // initialize wakeword subsystem
    if (!wakeword_init())
    {
        // Non-fatal: button mode is a complete fallback with no wake-word dependency.
        ESP_LOGW(TAG, "wake-word model failed to load — WAKEWORD mode won't detect; BUTTON mode still works");
    }

    // initialize network
    if (net_init() != ESP_OK)   // only fails on a config error (missing creds) -- not fixable by retrying
    {
        peripherals_set_led_status(LED_STATUS_ERROR);
        ESP_LOGE(TAG, "WiFi config invalid — cannot bring up networking. Halting.");
        return;
    }

    // spawn the turn loop on its own task (see runloop_task's doc comment for the stack sizing)
    xTaskCreate(runloop_task, "runloop", 12288, NULL, 5, NULL);
}

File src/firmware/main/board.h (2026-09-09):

// Pin map for the Billy fish. Dev board is an ESP32-S3-WROOM-1 N8R8 (octal PSRAM); the
// board/billy main board (Rev.0/1) populates the N4R2 (quad PSRAM) variant.
// Values are GPIO numbers. Pin-selection rules are already honored: ADC1 for the photocell
// (ADC2 is unusable while WiFi is on), an RTC-capable GPIO for the deep-sleep-wake button, and
// no strapping/flash/USB pins used anywhere.
#pragma once

// 0 = original dev/bench build: both DRV8833s' nSLEEP tied together and both nFAULT tied
//     together (one GPIO each) -- no independent activation or per-chip fault detection.
// 1 = board/billy production PCB: each DRV8833 gets its own nSLEEP/nFAULT.
#define BOARD_REV 0

// Unwired board: For testing, define this to make the software testable even without
// things like the photocell and mic connected
#define BOARD_UNWIRED 0

// --- Amplifier: MAX98357A, I2S0 TX (playback) ---
#define BOARD_AMP_I2S_LRCLK    7
#define BOARD_AMP_I2S_BCLK    15
#define BOARD_AMP_I2S_DIN     16
#define BOARD_AMP_SD_MODE     17  // drive low to mute / power-down the amp (pops, deep sleep)

// --- Microphone: ICS-43434 / INMP441, I2S1 RX (capture) ---
#define BOARD_MIC_I2S_SCK      4
#define BOARD_MIC_I2S_WS       6
#define BOARD_MIC_I2S_SD       5  // mic L/R pin tied to GND -> left channel

// --- Motor drivers: 2x DRV8833 (three spring-return motors) ---
// Each motor is driven one direction only: IN1 = PWM, IN2 held low (the spring returns it).
// IN2 stays on a GPIO so reverse remains a firmware option if a motor is found reversible.
// drv1 drives mouth (AIN) and head (BIN); drv2 drives tail alone -- so nSLEEP/nFAULT are always
// grouped mouth+head vs. tail below. On rev.0 the two chips' nSLEEP are tied together and their
// open-drain nFAULT wire-OR'd together (one GPIO each, so both groups resolve to the same pin
// here); rev.1 gives each chip its own pair.
#define BOARD_MOUTH_IN1       10  // drv1 AIN1, PWM (LEDC): mouth open amount for lip-sync
#define BOARD_MOUTH_IN2       11  // drv1 AIN2, held low (mouth unidirectional; spring return)
#define BOARD_HEAD_IN1        12  // drv1 BIN1, PWM: head raise
#define BOARD_HEAD_IN2        13  // drv1 BIN2, held low (head unidirectional; spring return)
#define BOARD_TAIL_IN1        21  // drv2 AIN1, PWM: tail flap
#define BOARD_TAIL_IN2        47  // drv2 AIN2, held low (tail unidirectional; spring return)

#if BOARD_REV == 0
#define BOARD_MOUTH_HEAD_NSLEEP   14  // drv1+drv2 shared nSLEEP: high = enabled; low in deep sleep -> ~uA
#define BOARD_MOUTH_HEAD_NFAULT   48  // drv1+drv2 shared nFAULT, wire-OR'd (open-drain + pull-up): low = OCP/thermal/UVLO on either chip
#define BOARD_TAIL_NSLEEP         14  // same physical pin as BOARD_MOUTH_HEAD_NSLEEP -- rev.0 can't separate them
#define BOARD_TAIL_NFAULT         48  // same physical pin as BOARD_MOUTH_HEAD_NFAULT -- rev.0 can't separate them
#elif BOARD_REV == 1
#define BOARD_MOUTH_HEAD_NSLEEP   42  // drv1 nSLEEP: high = enabled; drive low in deep sleep -> ~uA
#define BOARD_MOUTH_HEAD_NFAULT   41  // drv1 nFAULT, open-drain + pull-up: low = OCP/thermal/UVLO
#define BOARD_TAIL_NSLEEP         40  // drv2 nSLEEP
#define BOARD_TAIL_NFAULT         39  // drv2 nFAULT, open-drain + pull-up
#else
#error "Unsupported BOARD_REV"
#endif

// --- Inputs ---
#define BOARD_BUTTON           2  // active-low + pull-up; has an EXTERNAL ~10k pull-up
#define BOARD_MODE_SW          1  // stock ON-ON DPDT, 2-position, one pole used: button-wake (floating/high) vs wakeword-wake (grounded/low); has an EXTERNAL ~10k pull-up
#define BOARD_PHOTOCELL_ADC    9  // ADC1 (ADC2 is unusable while WiFi is on)

// --- Status LED: WS2812-family single RGB pixel. Bench: DevKitC-1's onboard WS2812 (DIN only,
// VDD unswitched). Final board: a single WS2812B with VDD gated by BOARD_PERIPHERALS_EN
#define BOARD_STATUS_LED      38  // data (DIN), through a series resistor

// --- Peripherals enable: shared low-side gate for the status LED plus the photocell and
// Vmotor-sense dividers' GND returns -- high whenever the chip is running in either wake mode,
// low during BUTTON-mode deep sleep
#define BOARD_PERIPHERALS_EN   18

// --- Vmotor sense (J13): ADC1, resistor divider from Vdrive to GND -----------------------------
// Rev.0 boards populate this test-point footprint as a bare scope-probe header instead (150R
// series to the GPIO, 10k pulldown to GND, no divider) -- reads near 0 there, which is harmless.
#define BOARD_VMOTOR_ADC       8  // ADC1_CH7 (ADC2 is unusable while WiFi is on)

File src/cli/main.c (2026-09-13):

// Billy Bass -- CLI reference client (thin fish client), C port.
//
// Exercises the full backend voice pipeline from any host with a mic + speaker, so the
// STT -> brain -> TTS chain is validated end-to-end before any ESP32 exists. This client *is*
// the documented fish<->backend protocol contract that the ESP32 firmware reimplements
// (src/firmware/main/net.c).
//
// Turn pipeline: record -> STT -> shim (streams sentences) -> TTS per sentence -> play, with
// sentence 1 spoken while later sentences are still being generated/synthesized. A synth thread
// reads the shim's SSE stream and calls TTS one sentence at a time, handing finished audio to
// the main thread over a queue for playback -- the main thread plays while the worker keeps
// pulling the next sentence ahead of it.
#include "audio_io.h"
#include "http.h"
#include "wav.h"

#include <math.h>
#include <pthread.h>
#include <signal.h>
#include <stdbool.h>
#include <stdio.h>
#include <stdlib.h>
#include <string.h>
#include <time.h>

#define DEFAULT_VOICE       "am_onyx"   // used only if the shim omits "voice" and --voice wasn't given
#define STT_TIMEOUT_MS      60000
#define RESPOND_TIMEOUT_MS  120000
#define TTS_TIMEOUT_MS      120000
#define RESET_TIMEOUT_MS    10000

// main() owns the process signal disposition, so the handler and its flag stay here.
volatile sig_atomic_t g_interrupted = 0;

static void handle_sigint(int sig)
{
    (void) sig;
    g_interrupted = 1;   // async-signal-safe: sig_atomic_t write only, no I/O or allocation here
}

static bool interrupted(const volatile void *ctx)
{
    const volatile sig_atomic_t *flag = ctx;
    return *flag != 0;
}

static double now_seconds(void)
{
    struct timespec ts;
    clock_gettime(CLOCK_MONOTONIC, &ts);
    return (double) ts.tv_sec + (double) ts.tv_nsec / 1e9;
}

static char *xstrdup(const char *s)
{
    size_t n = strlen(s) + 1;
    char *p = malloc(n);
    if (p) memcpy(p, s, n);
    return p;
}

// --- Playback queue: the worker thread pushes finished (sentence, audio) pairs as TTS synth
// completes; the main thread pops and plays them in order, one turn's worth at a time. ---------

typedef struct pb_item
{
    char           *sentence;
    int16_t        *audio;
    size_t          count;
    int             sample_rate;
    double          t_sent;   // TTS request sent, for the "sent->audio" latency print
    struct pb_item *next;
} pb_item_t;

typedef struct
{
    pb_item_t      *head, *tail;
    bool            done;
    pthread_mutex_t mu;
    pthread_cond_t  cv;
} pb_queue_t;

static void pb_queue_init(pb_queue_t *q)
{
    memset(q, 0, sizeof *q);
    pthread_mutex_init(&q->mu, NULL);
    pthread_cond_init(&q->cv, NULL);
}

static void pb_queue_destroy(pb_queue_t *q)
{
    pthread_mutex_destroy(&q->mu);
    pthread_cond_destroy(&q->cv);
}

static void pb_queue_push(pb_queue_t *q, pb_item_t *item)
{
    pthread_mutex_lock(&q->mu);
    item->next = NULL;
    if (q->tail) q->tail->next = item; else q->head = item;
    q->tail = item;
    pthread_cond_signal(&q->cv);
    pthread_mutex_unlock(&q->mu);
}

static void pb_queue_finish(pb_queue_t *q)
{
    pthread_mutex_lock(&q->mu);
    q->done = true;
    pthread_cond_signal(&q->cv);
    pthread_mutex_unlock(&q->mu);
}

// Blocks until an item is available or the queue is finished-and-drained (returns NULL then).
static pb_item_t *pb_queue_pop(pb_queue_t *q)
{
    pthread_mutex_lock(&q->mu);
    while (!q->head && !q->done) pthread_cond_wait(&q->cv, &q->mu);
    pb_item_t *item = q->head;
    if (item)
    {
        q->head = item->next;
        if (!q->head) q->tail = NULL;
    }
    pthread_mutex_unlock(&q->mu);
    return item;
}

// --- Synth worker: reads the shim's SSE stream and, for each sentence, synthesizes it via TTS
// before moving to the next -- same one-sentence-at-a-time pipelining as the Python reference's
// synth_worker() iterating its SSE generator. ----------------------------------------------

typedef struct
{
    const char *tts_url;
    const char *voice_override;
    pb_queue_t *queue;

    const char *shim_url;
    const char *session;
    const char *text;
    const char *language;
    cancel_check_t cancel;
    const volatile void *cancel_ctx;

    double t_prompt_sent;
    bool   first_sentence_seen;
    double ttfs;   // prompt-sent -> first-sentence latency (s)
} synth_ctx_t;

static bool on_sentence(const char *sentence, const char *voice, void *ctx_)
{
    synth_ctx_t *ctx = ctx_;
    if (cancel_requested(ctx->cancel, ctx->cancel_ctx)) return false;
    if (!ctx->first_sentence_seen)
    {
        ctx->ttfs = now_seconds() - ctx->t_prompt_sent;
        ctx->first_sentence_seen = true;
    }

    const char *chosen_voice = ctx->voice_override ? ctx->voice_override
                              : voice              ? voice
                                                    : DEFAULT_VOICE;

    double t_sent = now_seconds();
    uint8_t *wav = NULL;
    size_t wav_len = 0;
    if (!http_tts(ctx->tts_url, chosen_voice, sentence, &wav, &wav_len, TTS_TIMEOUT_MS,
                  ctx->cancel, ctx->cancel_ctx))
    {
        return !cancel_requested(ctx->cancel, ctx->cancel_ctx);
    }

    wav_pcm16_t pcm;
    bool parsed = wav_parse_pcm16(wav, wav_len, &pcm);
    free(wav);
    if (!parsed)
    {
        fprintf(stderr, "  [tts error: unparseable wav response]\n");
        return true;
    }

    pb_item_t *item = malloc(sizeof *item);
    item->sentence = xstrdup(sentence);
    item->audio = pcm.samples;
    item->count = pcm.count;
    item->sample_rate = (int) pcm.sample_rate;
    item->t_sent = t_sent;
    pb_queue_push(ctx->queue, item);
    return true;
}

static void *synth_worker(void *arg)
{
    synth_ctx_t *ctx = arg;
    ctx->t_prompt_sent = now_seconds();
    http_respond_stream(ctx->shim_url, ctx->session, ctx->text, ctx->language, on_sentence, ctx,
                        RESPOND_TIMEOUT_MS, ctx->cancel, ctx->cancel_ctx);
    pb_queue_finish(ctx->queue);
    return NULL;
}
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

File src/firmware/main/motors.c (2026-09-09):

#include "motors.h"
#include "hal.h"
#include "board.h"
#include "fish_config.h"
#include "peripherals.h"
#include "freertos/FreeRTOS.h"
#include "freertos/task.h"
#include "esp_log.h"

static const char *TAG = "motors";

// Each motor is IN1 = LEDC PWM, IN2 held low (spring-return; board.h). Every motor belongs to one
// of two DRV8833-chip groups (motors_group_t); nSLEEP/nFAULT are per-group.

#define MOTOR_PWM_FREQ_HZ     20000              // above audible range -- avoids motor whine
#define MOTOR_PWM_RESOLUTION  10
#define MOTOR_DUTY_MAX        ((1u << MOTOR_PWM_RESOLUTION) - 1)

typedef enum
{
    MOTOR_MOUTH = 0,
    MOTOR_HEAD  = 1,
    MOTOR_TAIL  = 2,
} motor_channel_t;

#define MOTOR_MASK(ch)  (1u << (ch))
#define GROUP_MASK(grp) (1u << (grp))

// nFAULT is unreliable--asserting when unexpected. We'll ignore it for now.
#define MOTORS_DEBUG_IGNORE_NFAULT 1

static const struct
{
    int      nsleep_pin;
    int      nfault_pin;
    uint32_t channel_mask;
} s_groups[MOTORS_GROUP_COUNT] = {
    [MOTORS_GROUP_MOUTH_HEAD] = { BOARD_MOUTH_HEAD_NSLEEP, BOARD_MOUTH_HEAD_NFAULT,
                                   MOTOR_MASK(MOTOR_MOUTH) | MOTOR_MASK(MOTOR_HEAD) },
    [MOTORS_GROUP_TAIL]       = { BOARD_TAIL_NSLEEP, BOARD_TAIL_NFAULT, MOTOR_MASK(MOTOR_TAIL) },
};

static const motors_group_t s_channel_group[3] = {
    [MOTOR_MOUTH] = MOTORS_GROUP_MOUTH_HEAD,
    [MOTOR_HEAD]  = MOTORS_GROUP_MOUTH_HEAD,
    [MOTOR_TAIL]  = MOTORS_GROUP_TAIL,
};

typedef struct
{
    bool     fault_latched;
    uint32_t fault_commanded_mask;
} group_fault_state_t;

static group_fault_state_t s_fault_state[MOTORS_GROUP_COUNT];
static uint32_t     s_commanded_mask;
static uint32_t     s_fault_count;
static uint32_t     s_pending_report_mask;   // groups newly latched since the task last drained
static TaskHandle_t s_fault_task;

static const char *group_name(motors_group_t grp)
{
    return grp == MOTORS_GROUP_TAIL ? "tail" : "mouth/head";
}

static void motor_fault_isr(void *arg)
{
    // Stop the affected group(s) before doing any bookkeeping. The GPIO ISR service is
    // deliberately installed without ESP_INTR_FLAG_IRAM, so this handler and hal_gpio_set need
    // not live in IRAM.
    uint32_t group_mask = (uint32_t) (uintptr_t) arg;
    bool any_newly_latched = false;

    for (int g = 0; g < MOTORS_GROUP_COUNT; g++)
    {
        if (!(group_mask & GROUP_MASK(g)))
        {
            continue;
        }
#if !MOTORS_DEBUG_IGNORE_NFAULT
        hal_gpio_set(s_groups[g].nsleep_pin, false);
#endif
        if (!__atomic_exchange_n(&s_fault_state[g].fault_latched, true, __ATOMIC_ACQ_REL))
        {
            any_newly_latched = true;
            __atomic_store_n(&s_fault_state[g].fault_commanded_mask,
                             __atomic_load_n(&s_commanded_mask, __ATOMIC_RELAXED) & s_groups[g].channel_mask,
                             __ATOMIC_RELAXED);
            __atomic_fetch_or(&s_pending_report_mask, GROUP_MASK(g), __ATOMIC_RELAXED);
        }
    }
    if (!any_newly_latched)
    {
        return;
    }
    __atomic_add_fetch(&s_fault_count, 1, __ATOMIC_RELAXED);

    BaseType_t higher_priority_task_woken = pdFALSE;
    vTaskNotifyGiveFromISR(s_fault_task, &higher_priority_task_woken);
    portYIELD_FROM_ISR(higher_priority_task_woken);
}

static bool motor_pin_fault_active(int nfault_pin)
{
    return !hal_gpio_get(nfault_pin);
}

static bool motor_group_faulted(motors_group_t grp)
{
#if MOTORS_DEBUG_IGNORE_NFAULT
    return false;
#else
    return __atomic_load_n(&s_fault_state[grp].fault_latched, __ATOMIC_ACQUIRE);
#endif
}

static bool motor_any_group_faulted(void)
{
    for (int g = 0; g < MOTORS_GROUP_COUNT; g++)
    {
        if (motor_group_faulted(g))
        {
            return true;
        }
    }
    return false;
}

static bool motor_any_pin_fault_active(void)
{
    for (int g = 0; g < MOTORS_GROUP_COUNT; g++)
    {
        if (motor_pin_fault_active(s_groups[g].nfault_pin))
        {
            return true;
        }
    }
    return false;
}

static bool motor_set_duty(motor_channel_t ch, uint32_t duty)
{
    motors_group_t grp = s_channel_group[ch];
    if (duty > MOTOR_DUTY_MAX) duty = MOTOR_DUTY_MAX;
    if (duty > 0 && motor_group_faulted(grp))
    {
        return false;
    }
    hal_pwm_set_duty(ch, duty);
    if (duty > 0)
    {
        __atomic_fetch_or(&s_commanded_mask, MOTOR_MASK(ch), __ATOMIC_RELAXED);
    }
    else
    {
        __atomic_fetch_and(&s_commanded_mask, ~MOTOR_MASK(ch), __ATOMIC_RELAXED);
    }
    if (duty > 0 && motor_group_faulted(grp))
    {
        hal_pwm_set_duty(ch, 0);
        __atomic_fetch_and(&s_commanded_mask, ~MOTOR_MASK(ch), __ATOMIC_RELAXED);
        return false;
    }
    return true;
}

static void motor_clear_all_duties(void)
{
    hal_pwm_set_duty(MOTOR_MOUTH, 0);
    hal_pwm_set_duty(MOTOR_HEAD, 0);
    hal_pwm_set_duty(MOTOR_TAIL, 0);
    __atomic_store_n(&s_commanded_mask, 0, __ATOMIC_RELAXED);
}

static void motor_clear_group_duties(motors_group_t grp)
{
    for (int ch = 0; ch < 3; ch++)
    {
        if (s_channel_group[ch] != grp)
        {
            continue;
        }
        hal_pwm_set_duty(ch, 0);
        __atomic_fetch_and(&s_commanded_mask, ~MOTOR_MASK(ch), __ATOMIC_RELAXED);
    }
}

static void motor_fault_task(void *arg)
{
    (void) arg;
    for (;;)
    {
        ulTaskNotifyTake(pdTRUE, portMAX_DELAY);
        uint32_t report_mask = __atomic_exchange_n(&s_pending_report_mask, 0, __ATOMIC_ACQ_REL);
        float vmotor = peripherals_read_vmotor_volts();
        for (int g = 0; g < MOTORS_GROUP_COUNT; g++)
        {
            if (!(report_mask & GROUP_MASK(g)))
            {
                continue;
            }
#if !MOTORS_DEBUG_IGNORE_NFAULT
            motor_clear_group_duties(g);
#endif
            uint32_t mask = __atomic_load_n(&s_fault_state[g].fault_commanded_mask, __ATOMIC_RELAXED);
            ESP_LOGE(TAG,
                     "nFAULT #%u on %s: %s; commanded mouth=%d head=%d tail=%d, Vmotor=%.2fV",
                     (unsigned) __atomic_load_n(&s_fault_count, __ATOMIC_RELAXED), group_name(g),
                     MOTORS_DEBUG_IGNORE_NFAULT ? "motors left running" : "motors parked",
                     (mask & MOTOR_MASK(MOTOR_MOUTH)) != 0,
                     (mask & MOTOR_MASK(MOTOR_HEAD)) != 0,
                     (mask & MOTOR_MASK(MOTOR_TAIL)) != 0, vmotor);
        }
    }
}
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

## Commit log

2026-07-23 Bring up I2S mic + amp with a bench self-test; size flash to 8MB
    [partitions.csv]
2026-07-23 Add end-to-end voice loop on ESP32: VAD capture, whisper STT, shim SSE, Kokoro TTS playback
2026-07-23 Add button + mode-switch activation with live mode switching to firmware wake path
2026-07-25 Swap in trained hey-billy wake-word model and clean up stale doc references in firmware comments
    [board.h, hal.c]
2026-07-26 Add WS2812 status LED showing boot/wifi/idle/listen/think/speak/error state
    [board.h, hal.c, main.c]
2026-07-28 Add motor drivers (2x DRV8833/LEDC PWM) with tail/head/mouth choreography, verified end-to-end on the bench
2026-07-29 Wire up the photocell ADC read, logged once at boot with no consumer yet
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2026-07-30 Add motor combined-load stress test; settle the tail flap before LISTEN's VAD starts
2026-07-30 Implement button-mode deep sleep, wake into ACTIVATE on button-caused reboot
    [board.h, hal.c]
2026-07-30 Photocell read API, 3-level mouth gate, drop OTA; update docs for Stage 4 decisions
    [partitions.csv]
2026-07-30 Gate button wake events on photocell brightness to reject dark-room false positives
2026-07-30 Mode-switch flip now wakes deep sleep and re-idles the runloop; drop the post-wake rest beat
    [board.h, hal.c]
2026-07-30 Collapse the runloop state machine into a plain turn loop; add capture-failure reboot and backend error tones
    [hal.c]
2026-07-30 Drop audio_buf_free wrapper; free samples directly at call sites
2026-07-30 Distinguish recoverable vs. reboot-worthy errors across audio/TTS/STT paths
    [hal.c]
2026-07-30 Change FISH_STATUS_WIFI_WAIT to FISH_STATUS_NET_WAIT and swap white with orange status
    [hal.c, main.c]
2026-07-31 Trim project READMEs to current-state HOWTOs, add firmware/clean.sh, refine Billy's persona
2026-07-31 Cap firmware flash budget to 4 MB to bench-test the N4R2 module candidate
    [partitions.csv]
2026-08-02 Swap head/tail motor GPIO assignment so head gets its own DRV8833 with a spare channel, and swap mic SCK/SD pins to simplify board layout
    [board.h]
2026-08-02 Point gitignore at .devdocs/ and board/tmp/ to match the new dev-doc and scratch-import layout
2026-08-02 Initial PCB design
    [billy.kicad_pcb, billy.kicad_sch]
2026-08-02 Add gated status LED (WS2812, low-side FET VDD switch) to schematic/board and firmware
    [billy.kicad_pcb, billy.kicad_sch]
2026-08-02 Complete board layout, assign LCSC part numbers, verify footprints; passes DRC
    [billy.kicad_pcb, billy.kicad_sch]
2026-08-02 Lower photocell wake threshold 100->50 to fix bench false negatives
    [hal.c]
2026-08-03 Fix some minor ERC and DRC checks
    [billy.kicad_pcb, billy.kicad_sch]
2026-08-04 Switched to Micro-USB 2.0
    [billy.kicad_pcb, billy.kicad_sch]
2026-08-04 Add fiducials and thermal vias, clean up USB diff pair routing
    [billy.kicad_pcb]
2026-08-04 Populate MPM3610 AAM resistor (R13, 82k) to enable light-load power-save mode
    [billy.kicad_pcb, billy.kicad_sch]
2026-08-04 Add 3D models for IC1, U2-U4, F1/F2, J5 (missing/stale library references)
    [billy.kicad_pcb]
2026-08-04 Tighten board to JLCPCB fab limits and add BOOT/TTL header pins
    [billy.kicad_pcb, billy.kicad_sch]
2026-08-05 Replace MPM3610 buck with Diodes AP63201, remove stale QFN-20 footprint
    [billy.kicad_pcb, billy.kicad_sch]
2026-08-05 Consolidate decoupling caps to one 0603 10uF part across buck and rail bypass positions
    [billy.kicad_pcb, billy.kicad_sch]
2026-08-05 Bump MX74610 charge-pump caps from 6.3V to 25V to fix zero-margin voltage rating
    [billy.kicad_sch]
2026-08-05 Shrink Vdrive/+3.3V/battery-input traces from 1mm to 0.5mm, trim track-width presets
    [billy.kicad_pcb]
2026-08-05 Fix capacitor specs: X7R/50V charge-pump caps, Panasonic bulk cap, consolidated VINT decoupling
    [billy.kicad_pcb, billy.kicad_sch]
2026-08-05 Correct MicroUSB connector. Correct MX74610T value
    [billy.kicad_pcb, billy.kicad_sch]
2026-08-06 Add some primary and alternate part numbers
    [billy.kicad_pcb, billy.kicad_sch]
2026-08-06 Simplify power-input topology: wall leg direct to Vdrive, repurpose freed diode/FET for USB-motor rail isolation
    [billy.kicad_pcb, billy.kicad_sch]
2026-08-06 Swap AO3400A to AOSS32334C: same AOS SOT-23 N-MOSFET, better Rds(on)/current, step 1 of LM74700-Q1 migration
    [billy.kicad_pcb, billy.kicad_sch]
2026-08-06 Migrate to LM74700-Q1 ideal diodes, complete board layout, drop unused MX74610T symbol
    [billy.kicad_pcb, billy.kicad_sch]
2026-08-07 Rewire GPIO17/18/8/48 for real amp SDMODE, LED_EN, misc probe, and NFAULT; swap I2S LRCLK/DIN
    [billy.kicad_pcb, billy.kicad_sch]
2026-08-07 Replace bare-pin misc probe (J13) with Keystone 5011 loop test point (TP5)
    [billy.kicad_pcb, billy.kicad_sch]
2026-08-07 Move client, firmware, and shim under src/; update path references
    [partitions.csv]
2026-08-07 Add part numbers for LM74700-Q1
    [billy.kicad_sch]
2026-08-07 Fix PCB DFM issues: widen undersized traces, untent vias-in-pad, tighten edge clearance
    [billy.kicad_pcb]
2026-08-08 Change some part numbers to active / in stock parts
    [billy.kicad_sch]
2026-08-10 Fix WAKEWORD-mode config staleness: fish_hal_wait_for_wake() no longer loops internally on photocell rejection
    [hal.c]
2026-08-10 Open board rev.1, move over to using AP63203 part
    [billy.kicad_pcb, billy.kicad_sch]
2026-08-10 Add Vmotor-sense divider on GPIO8 (R13/R15), shared across N8R8 dev and N4R2 main boards
    [billy.kicad_pcb, billy.kicad_sch]
2026-08-10 Cleaned up the parts table and added Digikey and Mouser part numbers for all parts
    [billy.kicad_sch]
2026-08-10 Let a button press abort in-progress mic capture, returning to idle
2026-08-10 Split hal.c into a generic low-level HAL plus device modules (motors, audio, sensors, status_led, activation)
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2026-08-12 Drop sensors_photocell_bright_enough()'s log-context param; restructure skip_idle in runloop_task
    [main.c]
2026-08-18 Rev 1 board updates
    [billy.kicad_pcb, billy.kicad_sch]
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2026-08-19 Replace battery-leg ideal diode with passive P-FET reverse-polarity protection
    [billy.kicad_pcb, billy.kicad_sch]
2026-08-19 Replace USB-leg ideal diode with a passive Schottky and drop its now-redundant bypass cap
    [billy.kicad_pcb, billy.kicad_sch]
2026-08-19 Switch battery-leg RP MOSFET from AOSS21311C to the more common AO3401A
    [billy.kicad_pcb, billy.kicad_sch]
2026-08-19 Replace repurposed MOTOR_RAIL->BUCK_IN leg's LM74700-Q1 with LTC4412 + AO3401A
    [billy.kicad_pcb, billy.kicad_sch]
2026-08-19 Switch status-LED gate FET (Q4) from AOSS32334C to the more common AO3400A
    [billy.kicad_pcb, billy.kicad_sch]
2026-08-19 Gate the photocell divider off BOARD_AWAKE_EN, shared with the status LED's supply gate
    [billy.kicad_pcb, billy.kicad_sch]
2026-08-19 Revert photocell wake threshold to a compile-time constant, drop the blocking config fetch it required
    [main.c]
2026-08-20 Gate Vmotor-sense divider off BOARD_PERIPHERALS_EN (Q7) and merge sensors/status_led into peripherals.c
    [billy.kicad_pcb, billy.kicad_sch]
2026-08-20 Replace fuse holders with SMD fuses to save cost
    [billy.kicad_pcb, billy.kicad_sch]
2026-08-20 Replace motor screw terminals with 1x6 block to save space and part count
    [billy.kicad_pcb, billy.kicad_sch]
2026-08-20 Cleaned up PCB file and removed unused embedded 3d models
    [billy.kicad_pcb]
2026-08-21 Switch PSRAM to quad mode for N4R2 and stop gating motors on rev.0's benign nFAULT trips
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2026-08-22 Swap head and tail control GPIOs
    [board.h]
2026-08-24 Split rev.1's DRV8833 nSLEEP/nFAULT per chip for independent motor group control
    [billy.kicad_pcb, billy.kicad_sch]
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2026-08-24 Split motor-rail bulk cap into two 220uF units, add solder-jumper Vmot->BUCK_IN bypass option
    [billy.kicad_pcb, billy.kicad_sch]
2026-08-24 Source U7 ESD diode from Slkor (verified drop-in) since ST USBLC6-2SC6 is out of stock
    [billy.kicad_sch]
2026-08-24 Final prep of rev.1 board
    [billy.kicad_pcb, billy.kicad_sch]
2026-08-26 Adapt VAD threshold to measured ambient noise so noisy rooms still detect end-of-speech
    [audio.c]
2026-08-26 Add SPICE simulation models for Q1/Q2/Q4/Q6/Q7/D2 and exclude mechanical parts from simulation
    [billy.kicad_sch]
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2026-09-04 Rev 2 board updates
    [billy.kicad_pcb, billy.kicad_sch]
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2026-09-12 Add motor output snubber caps (C27-C29) across mouth/head/tail for EMI suppression
    [billy.kicad_pcb, billy.kicad_sch]
2026-09-12 Remove JP1 debug solder jumper and reroute Vmot direct to motor caps
    [billy.kicad_pcb, billy.kicad_sch]
2026-09-12 Fix D2 footprint to SOD-323 (was SOD-123) and remove unused test points for rev.2
    [billy.kicad_pcb, billy.kicad_sch]
2026-09-13 Add --input-wav replay mode to both CLI clients; stop committing golden TTS fixtures
    [main.c]
2026-09-13 Add STEP file for microphone caddy
    [caddy.step]
